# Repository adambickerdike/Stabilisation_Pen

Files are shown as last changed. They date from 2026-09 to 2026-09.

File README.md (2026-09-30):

# Active stabilisation pen: engineering programme

A pen that actively moves its ink tip, and steadies its own body, to counter unwanted hand motion, supports people with Parkinson's-related writing difficulty, assists everyday handwriting and drawing, and captures notes with source-grounded AI assistance.

This repository holds the research and development package: the audit of the source report, evidence, requirements, physics, simulation, mechanics, electronics, firmware, ML, app, validation plans and decisions.

**Evidence status.** Everything here is **calculation, simulation, literature or proposed design**. Nothing has been built, and there are **no physical or human measurements**. Every figure carries a stamp saying what it is, and every result file records its code revision, parameter version, seeds and command.

**Astra publication handoff:** [PDF, GitHub-readable report, reproduction commands and result locations](docs/reviews/2026-09-30_astra_handoff.md). This publishes the implemented pass based on `4ad62b6`, including its corrected numerical evidence and explicit limitations.

**Implemented engineering review, 30 September 2026:** Start with [the new improvement report](docs/engineering_improvement_2026_09_30.md) and the detailed [integration audit](docs/integration_improvement_audit.md). The working tree now includes corrected mechanical load/support models, an extended-travel nib candidate and CAD, a grounded coarse-stage design, causal sensing and controller revisions, constrained accepted-text execution, and explicit correction acceptance. New experiments, rejected RL candidates, source hashes and verification reports are in `results/improvement/`. These are distinct models and evidence levels; do not combine their best numbers into a claim about one built pen. Historical results below remain available for comparison and require the qualifications in the new report.

**Independent review, 29 September 2026:** Read [the research and engineering review](docs/independent_research_review_2026_09_29.md) before using the earlier headline performance or runtime figures below. The later [integrated Rev J simulation, sections 5 and 8](docs/revJ_simulation.md) reports a static nib-load problem omitted by the earlier nose optimization: autowrite nose-coil power changes from 0.09-0.17 W in the simplified study to 2.13 W in the integrated study. Independent statics reproduce approximately 4.717 / 1.628 / 0.166 W of holding loss at 35 / 50 / 75 degrees with the stated geometry. These are calculations on unmeasured inputs, not hardware results. The review prioritizes load balancing, real page-relative sensing, an optional collar/body experiment, and equal-mass comparisons for the inertial tail. Earlier studies remain here as historical evidence; their claims require reconciliation with the integrated findings.

## Start here

| If you want… | Read |
|---|---|
| **On your computer:** open `START_HERE.html` for one-click links to the claims register, the explainer, the spelling prototype and the latest studies | `START_HERE.html` |
| **The latest improvement work:** proposed fine nib, grounded accepted-writing mechanism, causal controllers, physically constrained planning and verification | [`docs/engineering_improvement_2026_09_30.md`](docs/engineering_improvement_2026_09_30.md) |
| **Users and market (round 5, study U):** do people still write by hand, who would pay, what the alternatives are, the go/no-go criteria and the pen vs typing vs dictation comparison | [`docs/market_and_users.md`](docs/market_and_users.md); instruments in [`results/market/`](results/market/) |
| **The nib, optimised (round 5, study N):** Rev K's nib and the independent pass's candidates under one matched model, a search of 13,200 designs, and the recommended ±1.5 mm nib with CAD | [`docs/nib_optimisation.md`](docs/nib_optimisation.md); STEP files in [`results/nibopt/`](results/nibopt/) |
| **The first bench build (round 5, study H):** what to buy and build first, what it costs, how long it takes and what each test decides | [`docs/bench_build_plan.md`](docs/bench_build_plan.md); parts lists and templates in [`results/benchbuild/`](results/benchbuild/) |
| **A moving-paper writing surface (round 5, study P):** a desk platen that moves the paper under the pen, for severe tremor (reach) and for writing accepted words without pushing the hand; simulated on real recorded writing and tremor, with CAD | [`docs/platen_concept.md`](docs/platen_concept.md); results and STEP in [`results/platen/`](results/platen/) |
| **Which earlier results survive realistic sensing (round 5, study X):** the headline simulations rerun with causal sensing, the corrected nib loads and page model v2, case by case after reproducing the old numbers first; six code defects found and fixed (DEC-076) | [`docs/rebaseline.md`](docs/rebaseline.md); results in [`results/rebaseline/`](results/rebaseline/) |
| **The current upstream baseline, Rev K:** integrated balanced nib, its layout and unresolved fit/sensing issues | [`docs/revK_design.md`](docs/revK_design.md); read the new improvement report before quoting its budgets |
| The earlier Rev J design: ±6 mm moving nose, optional grounded heel and reaction-mass tail; historical whole-pen simulations | [`docs/revJ_concept.md`](docs/revJ_concept.md); plan [`docs/revJ_plan.md`](docs/revJ_plan.md); integrated design [`docs/revJ_design.md`](docs/revJ_design.md); the 3-D explainer [`viewer/explainer/`](viewer/explainer/build.py) |
| The Rev J studies | tip [`docs/nose_v2.md`](docs/nose_v2.md), heel [`docs/grounded_drive.md`](docs/grounded_drive.md), tail [`docs/inertial_endcap.md`](docs/inertial_endcap.md), algorithms and AI [`docs/ai_control_v2.md`](docs/ai_control_v2.md), physics simulator [`docs/sim_v2.md`](docs/sim_v2.md) |
| The previous design, Rev H (bigger grip, ±3 mm nose): what is inside, how much it helps each condition | [`docs/revH_concept.md`](docs/revH_concept.md) |
| The recommended route: what to build, where custom hardware and our own data are unavoidable, what evidence each benefit needs | [`docs/recommendation.md`](docs/recommendation.md) |
| The slim pencil variant (Ø8.9 × 166 mm): exact forces, mechanisms with existing parts, what to make, AI guidance and autocorrect, sim-to-real, 3D replay | [`docs/pencil_concept.md`](docs/pencil_concept.md), [`viewer/`](viewer/build.py) |
| The verdict on the source report | [`docs/audit.md`](docs/audit.md), [`docs/corrections.csv`](docs/corrections.csv) |
| **Which numbers still stand:** every headline claim with its status (current, suspended, unproven) | [`docs/claims_register.md`](docs/claims_register.md) |
| The independent review of 29 September 2026 and our response to each finding | [`docs/reviews/`](docs/reviews/2026-09-29_review_response.md) |
| Current state, blockers and next actions | [`CHECKPOINT.md`](CHECKPOINT.md) |
| The system and its budgets | [`docs/architecture.md`](docs/architecture.md), [`docs/icd.md`](docs/icd.md) |
| Why things are the way they are | [`docs/decisions.md`](docs/decisions.md) (DEC-001…099) |
| What the simulations say | [`docs/sim_report.md`](docs/sim_report.md) |
| What may be claimed for each feature | [`docs/features.md`](docs/features.md) |
| The riskiest open questions | [`docs/research_questions.md`](docs/research_questions.md) |
| How to proceed | [`docs/plan.md`](docs/plan.md), [`validation/`](validation/README.md) |

## Historical conclusions and study summaries

The studies below used different mechanisms, sensor assumptions and evaluation protocols. Their numbers are preserved for provenance. The report linked above identifies changed code and the experiments that were actually rerun; a passing software test does not validate an older physical or clinical claim.

> **Correction, 29 September 2026.** The moving nose's coils must hold the ball against a static sideways push from the paper. The refill spring presses the ball along the tilted pen, and the paper pushes back partly sideways. This was left out of the power budgets.
>
> - **Rev J (C1S nose):** it costs 4.7 / 1.6 / 0.17 W at 35 / 50 / 75° pen angle (CALC; confirmed by the physics simulation and by an independent review). The coils would overheat within about a minute.
> - **Rev H (longer arm):** 0.13 W at 50° or more (CALC).
> - **What is suspended:** every battery and heat claim for Rev H, Rev J and Rev J.1. A load-balanced nib is being designed (study B).
>
> **Fix designed, 30 September 2026 (study B, DEC-050; CALC and SIM, nothing built).** A balanced nib, B1, carries the load mechanically. The refill slides ±1 mm on four thin wires, and its spring pushes the refill's rear end through a small face kept parallel to the paper, so the spring's push and the paper's push cancel at any angle. Holding heat is at most 1.6 mW (limit 100 mW), continuous power 7.6 mW, about 38 h per charge (CALC). The cost is reach: ±1.06 mm instead of ±6 mm, so the pen can no longer write whole words for the user (autowrite); that stays a bench research mode. The next prototype, **Rev K**, is the Rev J body with this nib, no heel wheel in the base pen and no tail.
>
> **Rev K laid out, 30 September 2026 (study K, DEC-062…066; CALC, nothing built).** Putting B1 into a whole pen found three things it could not do as drawn: its coils did not fit the bore at the stop, its moving coils had no leads, and the counter-face's push would buckle its wires. Rev K fixes them (coils that can be wound, beryllium-copper wires that double as the leads, a ball thrust guide), at about 2.2 × the copper loss. Rev K is 145.1 mm long, weighs 66.4 g and writes about **24–49 h per charge** with 1 mm of tremor; the finger over the coils stays below 38 °C in a 30 °C room. Of 59 fit checks, 9 fail and 21 are marginal: among them, the page sensor loses the page above 0.2 mm of lift, the fresh ink is harder to see than on Rev J.1, and the fingers sit 3.3 mm closer to the paper at a flat angle (`docs/revK_design.md`).
>
> Check [`docs/claims_register.md`](docs/claims_register.md) before quoting any number.

1. **The transverse load is dominated by N·cos θ, not friction** (COR-01). Holding power (F/(n·K_m))² therefore rules out direct drive at the tip (about 12 W). A front-pivot lever with a rear annular actuator brings it to about 0.5 W in contact at the design point. That is **above the 0.412 W a moving coil can dissipate continuously** (within it on average at 65 % pen-down). Skid and bias-actuator variants remain the product path (DEC-003, DEC-008; route in `docs/recommendation.md`).
2. **Intent separation, not mechanics or latency, limits free-writing assistance.**
   - In simulation, the mechanism could remove 70–80 % of tremor-induced ink error (oracle bound 0.22–0.32).
   - The causal estimators tested give no benefit below ~9 Hz on synthetic handwriting.
   - Guided (template) tasks work in simulation: circle 443 → 163 µm, spiral 382 → 112 µm.
   - Whether real handwriting is more separable is the decisive open question (EXP-H01 → E01).
3. **Parkinson's writing difficulty is mainly micrographia.** A ±0.5 mm stage cannot enlarge letters. PD support means cueing, feedback and practice, measured for lasting unassisted benefit, not immediate correction (DEC-002).
4. **Design errors found and fixed in this package** (calculation and simulation):
   - Nib-bounce instability from a measured-force contact feedforward (DEC-011).
   - Voltage-limited 11 Ω coil, rewound to 6 Ω (DEC-012). A later, fuller headroom check found 6 Ω still binds at 3.3 V in the hot, high-force corner (0.5 % of the thermal envelope) and 4 Ω does not; open until EXP-B03 winds both.
   - A thermal model left at the old 0.45 mm air gap: the moving-coil allowable is 0.412 W, not 0.455 W (v0.4.3).
   - Interface errors found by the firmware review: the ICD printed the inverse Jacobian and the wrong actuator-force sign (fixed in ICD v1.3; the simulator and firmware were right). Tilt-dependent γ is now computed from a stored stiffness ratio.
   - An axial suspension layout that closes the actuator gap: the refill now slides in the carrier (DEC-007 rev.).
   - A nose that touched the paper at every writing angle: the refill point now protrudes 5 mm (DEC-018).
   - Inertia understated by a point-mass approximation: 13.7 g, above the 12 g requirement.
   - The research circuit does not fit the 29 mm board in the CAD envelope. The package plan and a 41 mm board fit at 0.65 density (DEC-014, open).
5. **A pencil-sized version is possible only if the writing force bypasses the nib** (`docs/pencil_concept.md`, DEC-019 to DEC-022).
   - A nose skid carries the user's force and a light spring sets the nib force. The stage then holds 0.17 N instead of 0.76 N.
   - Four custom 2.6 mm piezo plates fit the 7.9 mm bore. They give ±277 µm of stroke under load at zero static power, in 12.2 g of CAD before wiring. A voice coil that fits would need 2.4 W.
   - The stroke margin is thin (±162 µm at −20 % tolerance). Tremor estimation is the same open problem as in Rev A. Re-optimising the stage with real parts (P0.2: custom plates, thicker leaves, charge-recovery drive) gives 212 µm in the worst corner instead of none and 2.7 h of assist instead of 0.5 h (`docs/opt_hardware.md`, DEC-030).
   - **The user has since chosen a bigger grip (DEC-029): the primary concept is now Rev H, where the whole front of the pen tilts to move the tip about ±3 mm. The pencil is the slim variant.**
   - The skid causes touchdown and lift tails: about 1.1 mm of extra ink per stroke. A tilt-adaptive front stop cuts this to 0.33 mm. A stage feed-forward in firmware, tuned by adjoint gradients and Bayesian search, then brings the ink at the transitions to 0.005–0.008 mm per stroke; bounce is its open risk (`docs/opt_touchdown.md`, DEC-026).
   - Paper capture needs a ≥ 120 Hz page sensor that does not yet exist at this size.
   - AI helps as a digital autocorrect (word errors 32 % → 10 %). Physical guidance toward AI-predicted letters does not help free writing: a correct prediction is already about 300 µm off, beyond break-even. Guidance toward known templates does help.
   - Weights, gyroscopes or a motorised grip inside the 20 g pencil leave 0.85–0.97 of the ink error with perfect knowledge, against 0.18–0.43 for the nib stage (`docs/inertial_stabilisation.md`). At the user's direction the bigger-grip pen has active inertial control of its body (item 7, DEC-033).
   - The accelerometer now drives the tremor tracker directly, with gyroscope compensation. It leaves 0.78 of the tremor-band error on average, against 0.85 before, and 0.58–0.71 at 8–12 Hz once calibrated per writer. Separating tremor from writing is still the limit (`docs/sensor_fusion_ai.md`, DEC-025). Re-optimising its settings with exact adjoint gradients gives 0.86 instead of 0.91 for the default set, and 0.67 instead of 0.79 at 8–12 Hz; learned trackers were not better at equal false correction (`docs/opt_tracker.md`, DEC-028).
6. **The simulator can be calibrated from the planned bench work, and the twin experiments say how well** (`docs/sim_to_real.md`, DEC-023).
   - On 15 blind simulated plants the protocol experiments recover every model parameter to ≤ 1.6 % in about 1.5 h of bench time per build.
   - The calibrated twin then predicts the oracle ratio within ±0.1 for 14 of 15 plants, against 4–5 uncalibrated.
   - The same work found that the frozen tremor estimator degrades on randomised plants (median ratio 0.88 at 9 Hz), and that the existing Monte Carlo lets the controller see true plant values.

7. **Rev H, the bigger-grip pen, was the primary design until Rev J (item 8)** (DEC-029, DEC-032, DEC-033; `docs/revH_concept.md`). All simulation and calculation.
   - Ø22 × 170 mm, 75 g, or 103 g with the inertial module. The fingers hold a fixed sleeve whose front ring rests on the paper and carries the writing force. The whole front of the pen (the nose, holding the refill) tilts on a flexure gimbal, driven by two pairs of flat voice coils, so the ink tip moves up to ±3 mm: ten times the pencil's stage. About 0.08 W, about 27 h of writing.
   - A rear inertial module (19.8 g tungsten slug moved ±2.75 mm on two axes) pushes the whole pen against the shake. On top of the nose it adds 6–17 % further reduction depending on the grip. It is fitted in the first prototype; the product keeps it if the grip measurement (EXP-I01) and the bench test (EXP-I06) confirm ≥ 10 %. A plain weight made the ink worse in 38–42 % of 8–12 Hz cases and is not used.
   - With perfect knowledge of the tremor the nose removes 87–99 % of the ink error up to 2 mm, and the app reads 98–100 % of words. With today's accelerometer tracker: 22–50 % at 8–10 Hz (words read at 10 Hz, 1 mm: 54 → 87 %), and nothing at 4–6 Hz. **The tracker, not the mechanism, is the limit** (`docs/opt_inertial.md`, `docs/handwriting_outcomes.md`).
   - Parkinson's shrinking letters: a "write bigger" vibration cue kept letters at 5.2 mm instead of 4.2 mm, if people respond as small studies suggest. Poor handwriting: guidance brings the ink 24–61 % closer to the target letters while it is on (partial nose guidance 35 %, reading slightly better; full guidance reads worse); lasting benefit needs a human study (EXP-W04). Dyslexia: guidance never turned a wrong letter into the right one; the help is the app's spelling check, read-back and clean copy.
   - An optional desk board moves a permanent magnet under the paper to pull the pen along whole letters (0.4 N cap; `docs/guidance_board.md`, DEC-031).
   - AI letter prediction does not close the tracker's gap at 1–2 mm tremor: a correct predicted letter is 0.5–0.9 mm off because it is placed where the shaking tip lands; as a tracker input it closed 0 %, as nose guidance 1 %. The app's digital clean copy makes 97 % of words readable at 1–2 mm, against 30–59 % in the ink (`docs/ai_severe_tremor.md`, DEC-035).

8. **Rev J acts at the tip, the heel and the tail; it is now the primary design** (DEC-036…049; `docs/revJ_concept.md`). The user asked for far more physical effect, inertial movement of the whole pen, and a pen that can partly write for you. All calculation and simulation.
   - **The whole pen in the physics simulator (round 2, `docs/revJ_simulation.md`, DEC-046…049; SIM on synthetic writers and synthetic tremor, 6 test writers).** Readable words out of 10, ordinary pen → Rev J: essential tremor 2 mm at 8–12 Hz 5.4 → 10 (1 mm: 10 → 10; the ink error falls to 0.63 of the ordinary pen's); mild 0.3 mm: no change, no harm; **slow 4 Hz tremor: nothing** (the pen cannot yet tell it from writing; perfect knowledge would remove 90 %); severe 3 mm: 0.4 → 3.8 writing through it, 0.4 → 8.8 when the pen writes a text the writer chose (autowrite). Parkinson's practice loops: only the driven heel wheel keeps the last loop big (6.6 → 8.6 mm of 10). Dysgraphia: a half-way nose brings the ink 23 % closer to the copybook letters with no loss of readability. Dyslexia lead-through helps little (5.8 → 6.7); autowrite of the right spelling reads 10 of 10. Tremor-free writing: moved 0 mm by the nose, 0.41 mm by the heel wheel, so **the wheel is retracted by default** (DEC-048). The chosen tracker is the guarded tracker G4 (DEC-047). **Power:** the nose drew about 2.3 W in every mode, mostly to hold the ball against the static side load: writing time per charge is suspended until the load is carried mechanically (DEC-046, study B). RL was not trained yet.
   - **Real recorded data (study R, `docs/real_data.md`, DEC-054, DEC-055; SIM with real recorded inputs).** With real handwriting (UNIPEN: 14 adults with a ballpoint on paper), real Parkinson's tremor recorded at the pen tip, real essential tremor recorded at the hand, and a realistic page sensor, on held-out writers, texts and patients: real tip tremor is smaller than assumed (severe typically 1.7 mm, not 5–10 mm) and about twice as irregular as the model. **No tracker built so far makes the writing more readable on real tremor:** at the severe size, 0.5 of 10 words with an ordinary pen, 0.4 with Rev J's gated tracker, 0.2 with the learned TCN, and 7.0 with perfect knowledge of the tremor (6.8 without tremor). The ±6 mm nose has the reach; estimating real tremor in time is the missing piece. So the synthetic-tremor gains above are not claims about real tremor until a tracker passes on real inputs (DEC-055).
   - **Tracking real tremor (study E, `docs/real_tracker.md`, DEC-060, DEC-061; SIM with real recorded inputs).** Every kind of causal tracker was tried on study R's real inputs (filters, oscillator trackers, the pen's Kalman tracker with new gates, study W's candidate, small networks), tuned on the tuning writers only, frozen, and tested once on 9 held-out writers. **None passes DEC-055 yet.** The winner took about a third off the severe tip tremor (0.69 ×), but about 1 mm was left and words read stayed at 0.5 of 10; and it moved one writer's clean writing 0.49 mm, because that writer's large, fast letters looked like tremor to it. The reasons: handwriting moves in the same 4–8 Hz rhythm as tremor, real tremor wanders, and taking off a third of 1.7 mm is not enough. The delay is not the cause. A small network trained on real recordings looked better afterwards (0.60 ×, clean writing moved 2.5 µm) but must be tested again on new data (EXP-E10). Meanwhile the safe default tracker (G4) stays, help for severe tremor comes from the app (clean copy, spelling, completion), and the next nib stays at ±1 mm.
   - **The readable target and where the gap is (study F, `docs/readable_target.md`, DEC-067…069; SIM with real recorded inputs).** Driving the nose with perfect knowledge of the tremor and then spoiling it on purpose shows how much tremor may be left: **+2 readable words at the severe class need at most about 0.55 mm of the 1.7 mm left at the tip** (0.65 mm on the tuning writers, 0.55 mm on the test writers), and near-normal reading about 0.25 mm; the best causal tracker leaves 1.12 mm. **Predicting the tremor is not the problem** (over the pen's 4.9 ms horizon a simple predictor leaves 0.03 mm); **telling tremor from writing is**: with the tremor alone the pen's accelerometer gets to 0.29 mm, but once the person writes every estimator either backs off (about 1 mm left) or moves the writing. Calibrating the gate on each writer's own clean writing, raise-only, kept every writer's clean writing within 19 µm (information only). **Reach:** with a ±1 mm nib even perfect knowledge gains only 1.4 words at the severe class; ±1.5 mm gains 3.2, and a real tracker would need about ±2–3 mm. So Rev K's nib is for mild-to-moderate tremor and for proving the balanced nib; severe tremor needs both a separating estimator and more reach.
   - **Spelling help, prediction and clearer writing (study S, `docs/spelling_and_clarity.md`, DEC-056, DEC-057; CALC and SIM on real letters and real misspellings).** A separate language layer with three outputs (the ink, the transcript, and the pen's writing plan). Letters are read while they are written (82 % by the end of each letter for unseen writers). The spell checker catches 63 % of real children's misspellings when the letters are known (34 % when the pen reads them itself) at about 2 false alarms per 100 words; a tick at the next pause gets 3 of 10 misspellings fixed on paper (writer responses assumed). Word completion puts the word in the top 3 after one letter 52–56 % of the time. The shape assist does not make letters clearer (41.4 → 41.9 %), so it is not adopted; nearest-point close tracing is retired because it left parts of letters undrawn. The pen writes only text the writer accepted, and needs about ±4–6 mm of reach for a whole word. A prototype page to try it is in `ai3/demo/index.html`.
   - **Shifting the whole pen (study W, `docs/whole_pen_shift.md`, DEC-051…053; CALC and SIM).** At the user's request the study designed the strongest compact way to physically shift the whole pen: a collar you hold, with the inner pen swinging on a hinge 50 mm behind the tip, driven by a flat coil in the collar's back wall (±4 mm at the tip, 21.7 mm across, 40.1 g, only 0.055 W to hold at 50°). Weights, gyroscopes and pushing on the paper cannot do this job in a pen. **In simulation the collar did not beat Rev J's moving nose**, which already reaches ±6.57 mm (−5 % to +5 % against the same pen with the collar locked; the gate is 10 %), so the moving nose stays the part that shifts the ink, the collar is a bench experiment, and inertial tails are rejected for the product (DEC-051). What would make writing much better is knowing the tremor: at 3 mm, perfect knowledge leaves 0.14–0.24 mm and every word readable, against 1.1–1.4 mm with today's estimate (DEC-052).
   - **The balanced nib (study B, `docs/balanced_nib.md`, DEC-050; CALC and SIM).** Eleven ways to carry the paper's static sideways push were designed and optimised for the 24 mm pen and a 12–16 mm core. The winner, B1, is a two-axis translation nib on four titanium wires with flat moving coils (no magnetic pull) and a contact-driven counter-face that cancels the push at every tilt and roll (residual 5.3 mN, 6 % of the load). It holds with at most 1.6 mW and runs on 7.6 mW (Rev J's nose: 1.6 W at 50°); in the physics simulator it removes as much tremor as Rev J's nose up to 1 mm (words read 6.4 → 8.1 of 10, 8.9 with perfect knowledge) and never moved clean writing. Its reach is ±1.06 mm (a ±1.5 mm option doubles its small power). The biggest unknown is the lowest ink force a ballpoint writes with, which sets the power (8 mW at 0.15 N, 184 mW at 0.69 N). A slim core works only with piezo benders (±0.56 mm).
   - **The Rev K layout (study K, `docs/revK_design.md`, DEC-062…066; CALC, one SIM check).** B1 placed in the Rev J body with every part fitted, budgeted and drawn (CAD with STEP): 145.1 mm, 66.4 g (73.4 g with the heel module), balance point 74.9 mm from the tip; 23.5–48.6 h per charge with 1 mm tremor, 10.8–15.0 h of lead-through with the heel module; web 30.6 °C and front finger pad 35.9–37.6 °C in a 30 °C room; 226–501 USD per pen at 1,000 (assumption-heavy). It needed a buildable coil (force constant 0.334 N/√W, an upper bound), C17200 wires as the coil leads (beryllium: soldered or crimped only), a ball thrust guide for the counter-face couple, a counter-face head with three piezo motors, and a slower servo (40 / 46 Hz: +7 % ink error on tuning writers). The pen lift (0.5 mm in 0.18 s) serves the spelling cue. The heel wheel becomes a separate bench front (DEC-065). 9 of 59 fit checks fail.
   - **Physics first.** A handheld pen can push the hand only against a mass inside it, against the hand itself, or against the paper. A moving mass gives F = m(2πf)²X, which is tiny at handwriting frequencies (below about 5 Hz): the best 45 g end-cap moves the ink at most 0.21 mm and a gyroscope 1.06 mm, against the 2 mm needed (SIM). The paper, used as ground through a small wheel at the heel, gives 0.3–0.6 N on the hand (CALC on an assumed tyre friction, to measure in EXP-D01).
   - **Tip (nose v2, DEC-036).** The refill tilts on a gimbal 76.5 mm behind the ball, driven by a 2 × 2 magnet checkerboard across a spherical gap: ±6.0 mm of ball travel guaranteed over 35–75° of tilt (Rev H ±2.75 mm), in a Ø24 handle. A pen lift (electro-permanent brake and latch) separates strokes. **Autowrite** (a mode the user turns on) writes a known text in the writer's style while the hand sweeps along the line: 99.2 % of letters and 100 % of words read with up to 1 mm of tremor, 98 % at 2 mm; 2.5 mm letters at 3.7 letters/s (SIM).
   - **Heel (paper-grounded drive, DEC-037, DEC-048).** A 2 mm wheel in the skid ring; the first studies steered it by default (the cobot principle: it keeps the hand on the letter's path and cannot move the pen by itself); it is now retracted by default (above). In the simpler HW1-D model, Parkinson's "write big" loops reached 0.99 of the target height with steering alone (0.78 with nothing; contested by the physics simulation, where only the driven wheel kept the last loop big); tracing error 582 → 76 µm with the nose, although letters read fell from 92 % to 79 % (closer to the template is not more legible); lead-through drew a letter bowl within 0.3 mm in 93 % of runs. A writer who resists always wins: a letter the writer is set on was never turned into another (0 %).
   - **Tail (reaction-mass end-cap, DEC-038, DEC-045).** A tungsten slug moved ±4 mm on 5 Hz flexures in a detachable end-cap: in the simpler H1 model a further 5.6 / 16.8 / 18.3 % tremor reduction on top of the nose at grip splits 0.3 / 0.5 / 0.7 with Rev J.1's 29.6 g end-cap (8 / 18 / 20 % with the first 43 g design), and cues in pauses; **in the physics simulation, no gain** (0.67 of the ordinary pen's error with it, 0.65 without), and study W's tails never robustly beat the same mass locked, so **inertial tails are rejected for the product** (DEC-051). It cannot steer letters.
   - **Algorithms and AI (DEC-042, DEC-043, DEC-047).** In the simpler HW1 model a tremor-line detector switching on a listening (fixed-lag Kalman) tracker gave, for essential tremor 1–2 mm at 6–10 Hz, ink error 830 → 430 µm (Rev H's tracker 627) and words read 31 → 74 %, including 6 Hz where Rev H did nothing; in the physics simulation this tracker moved tremor-free writing by 59 µm (rule 25 µm), so the guarded tracker G4 replaces it there. A causal TCN reaches 278 µm but stays in shadow mode until real recordings. Delayed ink and next-letter steering did not help, and RL driving the nose read more words but moved clean writing too much; RL is used offline to design shared control. The app gains word completion and labelled style synthesis.
   - **Simulator v2 (DEC-040).** MuJoCo physics of the hand, pen, moving nose, refill and paper, with the heel wheel and end-cap as plug-ins, domain randomisation and a Gymnasium environment. On the earlier hand–pen model's 56 test cases it reproduces the uncorrected ink error within 3.1 % in every case, the perfect-knowledge ratio within ±0.03 in 52 and the tracker's ratio within ±0.05 in 50 (the misses are the Rev H tracker's frequency lock, not the plant); it converges and conserves energy; it also showed that the synthetic writers write at half adult speed with about ten times the measured 8–12 Hz motion, which makes tremor separation look harder than it probably is (refit on recordings, EXP-V03). Until bench identification, it ranks designs only (ASME V&V 40 context COU-1).
   - **Integration and Rev J.1 fixes (DEC-044, DEC-045; CALC).** Rev J.1 is Ø24 × 143.9 mm and 84.3 g, or 161.9 mm and 112.7 g with its lighter end-cap (target 120 g). It fixes what the first layout found: 75 µm gimbal strips carry the 12–22 N magnet pull (buckling 55 N); a low-power page sensor and datasheet-counted electronics give 8.5–9.7 h at 1 mm tremor; a 0.1 mm graphite sheet keeps the skin at 35.9 °C in a 30 °C room; a clear window shows the ink near the ball in 47 % of tilt × eye cases (was 22 %). All battery and heat numbers rest on the nose-coil power model, which left out the static side load; they are suspended (the physics simulation measured about 2.3 W).
   - **Round 4 (running, `docs/round4_plan.md`).** At the user's direction: shifting and pivoting the whole pen against large Parkinson's and essential tremor (gyroscopic tail, tuned mass, pivot grip, paper-grounded force, ink only when in reach); real recorded handwriting and tremor as simulation inputs; a physical spell checker, better word prediction and shape assist; results shown as one understandable number per condition.
   - **Measurement rigs (study M, `docs/measurement_rig.md`, DEC-058, DEC-059; PROPOSED DESIGN, CALC, synthetic checks).** Six bench rigs on one data-acquisition box and a converted 3-D printer, in the order the independent review asks: R9 contact and ink (gate G1: the lowest refill force that writes, the axial and paper-normal forces measured apart, and the static side load; it also runs EXP-J17), R10 page sensing on paper against DeltaPen, R11 recording pen and tablet protocol (real tremor and writing forces), R12 actuator coupons (G2), R13 loaded nib (G3, G4) and R14 grip simulant (G5: a moving collar or tail against the same mass locked). No rig exists yet; the firmware is written but not compiled for the board.
   - Rev H corrections found on the way (DEC-041): the nose actuator's force constant is 0.19 N/√W by an image-method model, not 0.47; the refill's front stop must follow the nose; the ink-force spring needs a fatigue rating.

**Where the simulations are, and what the optimisation studies found:** [`docs/optimisation.md`](docs/optimisation.md). The 3D replay page is `viewer/index.html` (`python3 viewer/build.py --variant Q`); the Rev J explainer is `viewer/explainer/index.html` (`python3 viewer/explainer/build.py`).

## Completion table

States: **drafted** (text or design, not run) · **executable** (code runs, results depend on unverified inputs) · **executed** (run here; outputs in `results/`) · **hardware pending** · **measured** (none yet).

| Brief area | Deliverable | State | Evidence |
|---|---|---|---|
| 1 Research | Audit and recalculation of the report (37/37 numbers reproduce; 28 corrections) | executed | `analysis/audit_recalc.py` → `results/audit/` |
| 1 Research | Evidence ledger (795 sources, 8 streams) and synthesis | drafted | `docs/evidence.csv`, `docs/research_synthesis.md` |
| 1 Research | Ranked research questions with decisive experiments | drafted | `docs/research_questions.md` |
| 2 Mechanics | Parametric CAD (Rev A, Rev A.1) with interference checks, STEP, drawings | executed | `mechanics/cad/`, `results/cad/` |
| 2 Mechanics | Flexures, tolerance stacks (S1–S6), mass/CoM budget, configuration trade | executed | `mechanics/`, `results/mechanics/`, `results/trade/` |
| 2 Mechanics | Stage-A loaded bench rig (dimensioned concept CAD) | executed (design) · hardware pending | `mechanics/cad/bench_rig.py`, `results/cad/drawing_bench_rig.png` |
| 3 Electronics | KiCad 8 schematic: 11 sheets, regenerated deterministically; ERC 0 errors; netlist cross-check pass; PDF; BOM with VERIFY/SELECT | executed | `electronics/kicad/`, `electronics/bom_revA.csv` |
| 3 Electronics | Drive/sense calculations, including the supply-headroom assessment of the winding (6 Ω binds at 3.3 V in the hot, high-force corner; 4 Ω does not); ngspice drive stage incl. fault; placement study | executed | `electronics/calcs/`, `electronics/spice/`, `results/electronics/` |
| 3 Electronics | PCB layout and fabrication outputs | **not started** (blocked by DEC-014) | `electronics/README.md` E-1 |
| 4 Simulation | Coupled pen–hand–paper model M1: 12 verification tests; tuning/test split; grid, Monte Carlo, sensitivity, failures, design sweeps, frequency-gate diagnostic | executed | `sim/`, `results/sim/`, `docs/sim_report.md` |
| 4 Simulation | EM field models; thermal network with a two-node reduction for the firmware governor | executed | `analysis/`, `results/em/`, `results/thermal/` |
| 4 Simulation | Validation plan per model | drafted | `docs/physics.md` (table), `validation/` |
| 5 ML | Synthetic data pipeline with writer-disjoint splits; six conventional baselines tuned on validation; causal TCN; int8 quantisation (no loss); C export bit-exact with the Python reference, also on emulated Cortex-M33; MCU budget (exported model without f_est: 16.2 k MAC, 7.3 kB weights, 0.58 kB RAM); model and dataset cards; 22 tests | executed (synthetic only) · real data pending (EXP-H01) | `ml/README.md`, `results/ml/` |
| 6 Firmware | C control core: 40 kHz current loop, 2 kHz stage task, Kalman and band-pass estimators, guided mode, Jacobian with tilt-dependent γ, two-node thermal governor, safety state machine, ML guard (ICD §5 v1.2), calibration records, ICD log writer. Parameters generated from the YAML with a freshness check; golden vectors and replays from the simulator; 60 test cases (1120 checks) pass on host (ASan/UBSan) and on emulated Cortex-M33; nRF5340 image builds (32.3 kB flash). Register-level drivers are stubs marked VERIFY | executed (host, emulator, build) · hardware pending | `firmware/README.md`, `results/firmware/` |
| 6 Product | ICD log reader/writer with CRC and resync (parses the firmware's golden log with zero issues); immutable content-addressed note store with provenance-carrying derived layers; segmentation; SVG rendering; recogniser interface (on-device adapter specified); FTS5 search with stroke citations; grounded assistant that refuses unsupported, uncited or clinical answers; capture-fidelity analysis; digital autocorrect as a derived layer; 147 tests | executed (synthetic data) · real recogniser pending | `app/README.md`, `results/app/` |
| 7 Validation | 227 experiments with criteria (172 bench/offline, 55 human) with procedures, equipment, uncertainty and decision rules, including the Rev J and Rev J.1 studies (EXP-D, K, N, L, V, J); 755 acceptance criteria (297 requirement, 135 derived, 323 hypothesis; checker passes) against 218 requirements; prototype stages A–D with gates; human study plan separating immediate assistance from lasting improvement; review of 33 document inconsistencies, now resolved or recorded | drafted · hardware and participants pending | `validation/README.md` |
| Pencil | Pencil-class concept: CAD (Q and L layouts, fit checks, STEP, drawings), mechanism study (forces, 12 mechanisms, drive power, drop), pencil model P1 (skid, spring-loaded refill, piezo stage; exact match with M1 when locked), page-sensor rate study, touchdown tails | executed (design, calculation, simulation) · hardware pending | `docs/pencil_concept.md`, `docs/pencil_mechanisms.md`, `mechanics/cad/pencil_revP.py`, `sim/pencil/`, `results/pencil/` |
| Pencil | AI prediction and guidance (text predictor, style templates, stroke continuation, closed loop on P1 and M1, deployment and ICD proposal) and app autocorrect | executed (synthetic data) · people pending (EXP-A02/A03) | `docs/ai_guidance.md`, `aiguide/`, `results/ai/` |
| Pencil | Inertial and pivot stabilisation study: hand-pen model H1 with pen tilt in a two-zone grip; weights, gyroscopes, CMGs, reaction wheels, grip sleeve, passive pivots | executed (simulation, calculation) · grip measurement pending (EXP-I01) | `docs/inertial_stabilisation.md`, `sim/handpen/`, `results/pencil/inertial*.json` |
| Pencil | Sensing and AI estimation: IMU parts and lever arm, acceleration-domain Kalman, WFLC/BMFLC, learned GRU, template prior, 20 s personal calibration, closed loop on P1 | executed (simulation) · real data pending (EXP-H01/E01) | `docs/sensor_fusion_ai.md`, `fusion/`, `results/fusion/` |
| Pencil | Slim pencil hardware optimisation (P0.2): differentiable design model (exact against design.py and the CAD), adjoint gradients, Bayesian optimisation and CMA-ES over real and supplier-standard parts, finalists ranked in P1, BOM, CAD with STEP | executed (calculation, simulation) · custom plates to quote (EXP-Q04) | `docs/opt_hardware.md`, `opt/hardware/`, `results/opt/hardware.json` |
| Pencil | Tracker optimisation: differentiable accelerometer Kalman filter (PyTorch, and a hand-written numba adjoint), tuning of all 23 settings by backpropagation through time, Pareto front against false correction, learned trackers on the tremor band, per-writer gradient tuning; recorded-data pipeline | executed (simulation) · real writing pending (EXP-E01) | `docs/opt_tracker.md`, `opt/tracker/`, `results/opt/tracker.json` |
| Pencil | Touchdown and lift optimisation: stage feed-forward, stop margin and servo retune; adjoint gradients of a differentiable reduced model (torch), ParEGO Bayesian optimisation and CMA-ES on P1; faster slide-sensor option | executed (simulation) · bench pending (EXP-Q08) | `docs/opt_touchdown.md`, `opt/touchdown/`, `results/opt/` |
| Pencil | 3D replay page of the simulated pencil with generated tables | executed | `viewer/` (`python3 viewer/build.py`) |
| Rev H | Bigger-grip pen: tip design A against B, adjoint design of the nose actuator, ParEGO tracker for ±3 mm, rear inertial module, gyroscope and passive-weight options, neural reaction-mass controller, envelope tiers, CAD with STEP (with and without the module), BOM, power; H1 extended with regression tests | executed (calculation, simulation) · grip and bench pending (EXP-I01, I05, I06) | `docs/opt_inertial.md`, `opt/inertial/`, `mechanics/cad/revH_pen.py`, `results/opt/inertial_opt.json`, `results/revH/` |
| Rev H | Handwriting outcomes per condition (essential tremor, Parkinson's micrographia, poor handwriting, dyslexia) in model HW1, cross-checked against P1; scorer for real recordings | executed (simulation) · people pending (EXP-W01…W05) | `docs/handwriting_outcomes.md`, `handwriting/`, `results/handwriting/` |
| Rev H | Guidance board: architecture comparison, magnet force maps, stage, Hall sensing, guidance control, CAD, BOM | executed (calculation, simulation) · hardware pending (EXP-G01…G07) | `docs/guidance_board.md`, `board/`, `mechanics/cad/guidance_board.py`, `results/board/` |
| Rev H | 3-D explainer: components, how it moves, before/after writing, evidence level of every number; smoke test | executed | `viewer/explainer/` (`python3 viewer/explainer/build.py`) |
| Rev H | AI help for severe tremor: letter prediction as a tracker prior and as nose guidance, a severe-tremor tracker setting, the app's digital clean copy; safety (wrong letters, agency, false correction); rules fixed on tuning writers | executed (simulation) · recordings pending (EXP-W02, EXP-A03) | `docs/ai_severe_tremor.md`, `aiprior/`, `results/aiprior/` |
| 4 Simulation | Sim-to-real: virtual bench with instrument models, blind identification of 15 plants in protocol order, bench-time study, calibrated-twin prediction gap, model-form diagnostics, piezo hysteresis identification, domain randomisation, hardware-in-the-loop specification; 22 tests | executed (twin experiments) · bench pending | `docs/sim_to_real.md`, `validation/sim_to_real.md`, `s2r/`, `results/s2r/` |
| Rev J | Plan and plain-words concept: what acts at the tip, heel and tail, results per condition, modes, whether it can write for you, what to test first | drafted | `docs/revJ_plan.md`, `docs/revJ_concept.md` |
| Rev J | Study D, paper-grounded heel drive: traction over the writer population, tyre mechanics, driven ball, omni-wheels, steered and braked wheels, controllable friction; differentiable design optimisation; guided, lead-through and resisting-writer runs; force cap and lateral release; CAD | executed (calculation, simulation) · friction and bench pending (EXP-D01…D07) | `docs/grounded_drive.md`, `drive/`, `results/drive/`, `mechanics/cad/heel_drive.py` |
| Rev J | Study K, inertial end-cap: force ceilings, CMA-ES and autograd design of reaction masses, gyroscopes (CMG), reaction wheels and pseudo-force cues; tremor on top of the nose; letter steering; CAD | executed (calculation, simulation) · grip pending (EXP-I01, K08) | `docs/inertial_endcap.md`, `endcap/`, `results/endcap/`, `mechanics/cad/endcap.py` |
| Rev J | Study N, nose v2: magnet-array field models (magpylib), CMA-ES and adjoint optimisation over multi-pivot and multi-coil candidates, front-end closure at ±3–8 mm, pen lift, autowrite planner and test grid; CAD | executed (calculation, simulation) · coupons pending (EXP-N01) | `docs/nose_v2.md`, `nose2/`, `results/nose2/`, `mechanics/cad/nose2.py` |
| Rev J | Study L, AI and control v2: tremor-line gate, gated listening tracker, learned estimators (TCN, transformer, hybrid), delayed ink, RL (PPO, SAC) in Gymnasium, next-letter and next-word prediction, sigma-lognormal style synthesis, shared-control arbitration | executed (synthetic data) · recordings pending (EXP-H01, EXP-L01…L08) | `docs/ai_control_v2.md`, `ai2/`, `results/ai2/` |
| Rev J | Study V, simulator v2: MuJoCo 3.6 hand–pen–paper model with the H1 contact law, reproduction of H1, time-step convergence, energy balance, gyroscope check, MyoSuite impedance, literature validation, Gymnasium environment with domain randomisation, plug-ins; ASME V&V 40 contexts of use | executed · bench identification pending (EXP-V01…V06) | `docs/sim_v2.md`, `sim2/`, `results/sim2/` |
| Rev J | Integrated design: front end, placement along the pen, refill and pen lift, mass, power, heat and cost budgets, magnetics, 38 fit checks, simulator parameters, CAD with STEP | executed (calculation) · hardware pending | `docs/revJ_design.md`, `revj/`, `results/revJ/`, `mechanics/cad/revJ_pen.py` |
| Round 4 | Study B, the balanced nib (after the independent review): eleven load-balancing mechanisms designed for the 24 mm pen and a 12–16 mm core, magnetics, flexures, fatigue, thermal and ink-force models, multi-objective optimisation, closed-loop simulation in sim2, CAD of the recommended nib B1, interface file `config/nib.yaml` | executed (calculation, simulation) · bench pending | `docs/balanced_nib.md`, `bnib/`, `results/bnib/`, `mechanics/cad/bnib.py` |
| Round 4 | Study W, shifting the whole pen against large tremor: tremor targets, grip pivoting, collar, tuned masses, gyroscopes, paper-grounded force and write-when-in-reach designed and optimised; closed-loop simulation against the same pen locked at three grips; real tremor sizes; CAD of the reference collar | executed (calculation, simulation) · bench pending | `docs/whole_pen_shift.md`, `wholepen/`, `results/wholepen/`, `mechanics/cad/wholepen.py` |
| Round 4 | Study S, spelling help, prediction and clearer writing: causal streaming letter recogniser, recognition-aware spell checker from real misspellings, physical cues, personal word completion, why close tracing lowers legibility, shape assist, accepted-word writing planner, three separated outputs; a self-contained prototype page | executed (calculation, simulation) · people pending | `docs/spelling_and_clarity.md`, `ai3/`, `results/ai3/` |
| Round 5 | Study N, the balanced nib optimised: the four existing nib designs under one matched model (gravity, face residual, writing drag, guide drag, nonlinear wires, fin-model temperature, weakest-point force constant × 0.7), guide-topology screen, NSGA-II search of 13,200 designs over reach, body, magnets, winding, wires, anchor, guide and moving mass, four candidates with CAD and pen budgets | executed (calculation) · coupon pending (EXP-NB01) | `docs/nib_optimisation.md`, `nibopt/`, `results/nibopt/`, `mechanics/cad/nibopt.py` |
| Round 5 | Study U, users and market: sourced prevalence and handwriting-use evidence, sizing model, competitor scan, customer-discovery pack (interview guides, survey, waitlist plan, recruitment and ethics), pre-registered go/no-go criteria, the pen vs typing vs dictation comparison design, business-model order | executed (literature and calculation) · discovery pending (EXP-U01…U06) | `docs/market_and_users.md`, `results/market/` |
| Round 5 | Study H, the first bench build plan: parts lists per gate with sourced prices, fabrication, safety (beryllium, magnets, the five-bar), test-to-decision map, budget and 12-week schedule, blank data templates, a synthetic pipeline check through the rig analyses | executed (plan) · nothing bought yet | `docs/bench_build_plan.md`, `results/benchbuild/` |
| Round 5 | Study P, the moving-paper platen: concept with sourced parts (voice-coil fine stage on a belt coarse stage, vacuum plate, palm rest, camera tip sensing, Z-drop lift), a moving-page plant coupled to HW1, tremor cancellation on real recorded inputs against the ±1.0 and ±1.5 mm nibs, accepted-word writing against the five-bar, sensitivity to friction coupling, camera and stage, product fit, CAD with STEP | executed (simulation with real recorded inputs, calculation) · bench pending (EXP-PL01…PL09) | `docs/platen_concept.md`, `platen/`, `results/platen/`, `mechanics/cad/platen.py` |
| Round 5 | Study X, the re-baseline: an impact register of all 69 simulation claims (29 rerun, 15 affected but not rerun with reasons, 23 unaffected, 2 superseded); sim2j's cards with causal sensing (Rev J + G4 0.61 of the ordinary pen, was 0.63), the balanced nib in sim2 with DEC-066's servo and the corrected loads, study F's reach with B1's servo and mass (±1.5 mm needed), studies R, E and F under page model v2 (conclusions stand); six defects in imported packages, fixed in their packages (DEC-076; full suite 958 passed) | executed (simulation, reproduction checks first) · bench pending (EXP-X01…X09) | `docs/rebaseline.md`, `rebaseline/`, `results/rebaseline/` |
| Round 4 | Study F, the readable target: tremor left at the tip against words read (amplitude, lag and random residuals; frozen on tuning writers, tested once), per-user gate calibration (information only), prediction vs sensing vs separation, the reach a nib needs | executed (simulation with real recorded inputs) · people pending (EXP-E20) | `docs/readable_target.md`, `readable/`, `results/readable/` |
| Round 4 | Study K, the Rev K integrated layout: B1 in the Rev J body, buildable coils, C17200 wire leads, ball thrust guide, counter-face head and pen lift, 59 fit checks, centring tolerances, mass, power and battery per mode, skin temperature, nib modes against the 2.5 × rule, cost, heel module, simulator parameters; CAD with STEP; a servo-bandwidth check in sim2 | executed (calculation, one simulation check) · bench pending (EXP-K20…K25) | `docs/revK_design.md`, `revk/`, `results/revK/`, `mechanics/cad/revK_pen.py` |
| Round 4 | Study E, tremor tracking on real data: filters, WFLC/BMFLC, oscillator trackers and EPLL, Kalman trackers with new gates, study W's GLG, networks trained on real and synthetic writing; delay analysis; pre-registered choice frozen on tuning writers and tested once on held-out writers; MCU cost | executed (simulation with real recorded inputs) · none passes DEC-055 | `docs/real_tracker.md`, `realtrack/`, `results/realtrack/` |
| Round 4 | Study R, real recorded data: real handwriting (UNIPEN hpb2, chosen by a kinematics rule), real Parkinson's and essential tremor, severity classes at the pen tip, a measured-error page sensor, a literal handwriting reader (TrOCR); held-out writers, texts and patients; the bridge from synthetic to real inputs; licences respected (only statistics of restricted data committed) | executed (simulation with real recorded inputs) | `docs/real_data.md`, `realdata/`, `results/realdata/` |
| Rev J | Study M, measurement rigs for the review's gates G1–G5 and page sensing: six rigs (R9–R14) on one 24-bit DAQ and a converted CoreXY printer; CAD with STEP files, drawings and fit checks; DAQ firmware (written, not compiled for the board); USB logger, unit conversion, clock sync, calibration, uncertainty budgets and every analysis, tested on synthetic data (49 self-test checks, 25 tests); offline tablet recorder; bill of materials; 17 experiments (EXP-T01…T17) | executed (design, calculation, synthetic checks) · hardware pending | `docs/measurement_rig.md`, `rig/`, `results/rig/`, `mechanics/cad/rig_*.py` |
| Rev J | Whole-pen closed loop in simulator v2: nose, heel wheel and end-cap together; trackers compared on tuning writers and frozen before the test; results cards per condition; power split; page-sensor error; writer model v2 | executed (simulation) · ET test writers 4–5, the second seed and RL training still to run | `docs/revJ_simulation.md`, `sim2j/`, `results/sim2j/` |
| — | Engineering recommendation: route, conflicting targets with limiting calculations, custom hardware, AI data needs, evidence per benefit | drafted | `docs/recommendation.md` |
| — | Interfaces, decisions, plan with effort ranges (100–174 pw) and quotation list, environment lock | drafted | `docs/icd.md`, `docs/decisions.md`, `docs/plan.md`, `ENVIRONMENT.md`, `requirements.txt` |

## Reproduce

Environment: [`ENVIRONMENT.md`](ENVIRONMENT.md) (Python 3.11 with `requirements.txt`; KiCad 8.0.9; ngspice 42; arm-none-eabi-gcc 13.2; QEMU 8.2).

```bash
python3 -m pip install -r requirements.txt
python3 analysis/audit_recalc.py                    # report recalculation
python3 -m pytest sim/tests -q                      # simulator verification
bash sim/run_all.sh                                 # simulation evidence chain (10-25 min)
python3 mechanics/cad/pen_revA.py --variant A1      # CAD, mass, interference
python3 mechanics/tolerance_analysis.py && python3 mechanics/mass_budget.py
python3 electronics/gen/design_revA.py              # schematic; then kicad-cli ERC/netlist (electronics/README.md)
python3 electronics/calcs/drive_sense.py
(cd electronics/spice && ngspice -b drive_stage.cir && python3 plot_drive_stage.py)
```

Pencil concept:

```bash
python3 mechanics/cad/pencil_revP.py --variant Q      # pencil CAD, fit checks, mass (also --variant L)
python3 analysis/pencil_mechanisms.py                 # forces, mechanisms, power (about 90 s)
python3 -m sim.pencil.run_study                       # pencil model P1 (about 95 s); tests: python3 -m pytest sim/pencil/tests -q
python3 -m sim.pencil.diag_touchdown_tails            # touchdown tails and the tilt-adaptive stop
bash aiguide/run_all.sh                               # AI prediction, guidance and autocorrect (about 15 min)
bash s2r/run_all.sh                                   # sim-to-real twin experiments (about 30 min on 2 processes)
python3 -m sim.handpen.run_study                      # weights, gyroscopes and pivots (about 5 min); tests: python3 -m pytest sim/handpen/tests -q
python3 -m fusion.run_study --workers 2               # accelerometer tracker and AI estimation (tests: python3 -m pytest fusion/tests -q)
python3 -m fusion.viz                                 # 3D replay of the tracker
python3 -m opt.hardware.run_study                     # slim pencil hardware optimisation (P0.2); tests: python3 -m pytest opt/hardware/tests -q
python3 -m opt.tracker.run_study                      # tracker tuned by adjoint and learned trackers (3-4 h on 2 cores); tests: python3 -m pytest opt/tracker/tests -q
python3 -m opt.touchdown.run_study                    # touchdown feed-forward and servo optimisation (about 1.5 h on 2 processes; --quick smoke run); tests: python3 -m pytest opt/touchdown/tests -q
python3 viewer/build.py                               # 3D replay page from the results
```

Rev H (bigger grip):

```bash
python3 -m opt.inertial.run_study                     # nose, tracker, inertial module (about 35 min; --quick about 2 min); tests: python3 -m pytest -q opt/inertial/tests
python3 mechanics/cad/revH_pen.py [--addon]           # Rev H CAD, fit checks, STEP (--addon: with the inertial module)
python3 -m handwriting.run_study                      # before/after writing per condition (--quick smoke run); tests: python3 -m pytest -q handwriting/tests
python3 -m board.run_study                            # guidance board (about 2-3 min); tests: python3 -m pytest -q board/tests
python3 -m aiprior.run_study                          # AI help for severe tremor (about 20 min; --quick about 5 min); tests: python3 -m pytest -q aiprior/tests
python3 -m opt.inertial.front_end --sens              # Rev H front-end closure and its sensitivity check (about 1 min)
python3 mechanics/cad/guidance_board.py               # board CAD and drawing
python3 viewer/explainer/build.py                     # 3-D explainer page from the results
```

Rev J (tip, heel and tail):

```bash
python3 -m drive.run_study                            # heel drive (about 50 min; --quick about 5 min); tests: python3 -m pytest -q drive/tests
python3 -m endcap.run_study                           # end-cap (about 75 min; --quick about 2.5 min); tests: python3 -m pytest -q endcap/tests
python3 nose2/run_study.py                            # nose v2 and autowrite (about 2-3 h; --quick about 1.5 min); tests: python3 -m pytest -q nose2/tests
python3 -m ai2.run_study --workers 1                  # AI and control v2 (about 4 h; --quick about 40 min); tests: python3 -m pytest -q ai2/tests
python3 -m sim2.run_study                             # simulator v2 (about 3 h; --quick); tests: python3 -m pytest -q sim2/tests
python3 -m revj.run                                   # integrated layout, budgets, simulator parameters (about 25 s); tests: python3 -m pytest -q revj/tests
python3 -m bnib.run_study                             # the balanced nib (a few hours in stages; --quick); tests: python3 -m pytest -q bnib/tests
python3 -m revk.run                                   # Rev K integrated layout and budgets (about 15 s; --quick); tests: python3 -m pytest -q revk/tests
python3 mechanics/cad/revK_pen.py --heel             # Rev K CAD, STEP files, drawing and solid checks (about 8 s)
python3 -m wholepen.run_study                         # shifting the whole pen (a few hours in stages; see docs/whole_pen_shift.md §9); tests: python3 -m pytest -q wholepen/tests
python3 -m ai3.run_study                              # spelling, prediction and clarity (several hours; --quick about 8 min); tests: python3 -m pytest -q ai3/tests
python3 -m realtrack.run                              # tremor tracking on real inputs (about 5 CPU h; --quick); tests: python3 -m pytest -q realtrack/tests
python3 -m readable.run                               # the readable target, per-user gates, the gap, reach (about 110 min on 2 workers; --quick about 3 min); tests: python3 -m pytest -q readable/tests
python3 -m nibopt.run                                 # nib optimisation (about 37 min from scratch; --reuse about 3 min; --quick under 1 min); tests: python3 -m pytest -q nibopt/tests
python3 mechanics/cad/nibopt.py --candidate all       # STEP, drawing and summary for each nib candidate (about 24 s)
python3 -m platen.run                                 # moving-paper platen (about 80 min from empty caches; each stage resumes; --quick under 2 min); tests: python3 -m pytest -q platen/tests
python3 mechanics/cad/platen.py                       # platen CAD: STEP, drawing and summary
python3 -m rebaseline.run                             # re-baseline under causal sensing (about 9.7 CPU h, 5 h on 2 jobs: --jobs 2; --quick about 27 min); tests: python3 -m pytest -q rebaseline/tests
python3 results/market/sizing_model.py              # market sizing (study U; arithmetic only, regenerates market_sizing.csv)
python3 results/benchbuild/tools/pipeline_check.py  # bench build: synthetic data through the rig analyses (study H; about 3 s)
python3 -m realdata.run                               # real recorded inputs (downloads the open datasets; about 2.5 h; --quick about 15 min); tests: python3 -m pytest -q realdata/tests
python3 -m sim2j.run_study                            # whole Rev J pen in simulator v2 (several CPU hours; one writer per process: SIM2J_WRITERS=4 ... --stages et); tests: python3 -m pytest -q sim2j/tests
python3 mechanics/cad/revJ_pen.py [--no-endcap]       # Rev J CAD, STEP and drawing
```

Firmware, ML and app have their own build and test commands in their READMEs.

## Repository map

`config/parameters.yaml` holds every parameter with unit, range, status and source (v0.4.4); `config/pencil.yaml` overlays it for the pencil concept (P0.1.2). The directories:

| Directory | Contents |
|---|---|
| `stabpen/` | Shared physics |
| `analysis/` | Audit, EM, thermal, trade |
| `sim/` | Coupled simulator (M1 in `sim/pensim/`, pencil model P1 in `sim/pencil/`) |
| `mechanics/` | CAD, flexures, tolerances, mass |
| `electronics/` | Schematic, calculations, SPICE, BOM |
| `firmware/` | Embedded control core |
| `ml/`, `data/` | Learned predictor pipeline, schemas |
| `app/` | Companion software |
| `aiguide/` | AI prediction, templates and guidance studies (pencil concept) |
| `fusion/` | Sensor models and tremor trackers |
| `opt/` | Optimisation studies: touchdown, tracker, slim hardware, Rev H inertial and front end |
| `handwriting/` | Handwriting outcomes model HW1 and the recording scorer |
| `aiprior/` | AI help for severe tremor: tracker prior, guidance, clean copy |
| `board/` | Guidance board study |
| `drive/` | Rev J heel drive (paper-grounded wheel) study |
| `endcap/` | Rev J inertial end-cap study |
| `nose2/` | Rev J nose v2 and autowrite study |
| `ai2/` | Rev J AI and control v2: trackers, learned estimators, RL, text prediction, style synthesis, shared control |
| `sim2/` | Simulator v2 (MuJoCo) with plug-ins and a Gymnasium environment |
| `revj/` | Rev J integration: layout, budgets, magnetics, simulator parameters |
| `sim2j/` | Rev J whole-pen closed loop in simulator v2 (round 2) |
| `bnib/` | The balanced nib (study B): load-balancing mechanisms, optimisation, simulation, the B1 design |
| `revk/` | The Rev K integrated layout (study K): nib in the pen, counter-face head, tolerances, fit checks, budgets, simulator parameters |
| `wholepen/` | Shifting the whole pen (study W): collar, tails, paper force, write-when-in-reach, closed-loop simulation |
| `ai3/` | Spelling help, prediction and clarity (study S), with the prototype page `ai3/demo/index.html` |
| `realtrack/` | Tremor tracking on real data (study E): estimators, gates, learned networks, the frozen test |
| `readable/` | The readable target (study F): residual sweeps, per-user gates, the prediction/separation split, reach |
| `nibopt/` | The balanced-nib optimisation (study N): matched model, reconciliation, guide screen, NSGA-II search, candidates, budgets |
| `platen/` | The moving-paper platen (study P): moving-page plant on HW1, camera predictor, tremor, accepted writing, sensitivity, concept calculations |
| `rebaseline/` | The re-baseline (study X): impact register, causal reruns of sim2j's cards, the balanced nib in sim2, reach with B1's dynamics, page model v2 on real inputs |
| `results/market/` | Users and market (study U): sizing model and CSV, competitors, interview guides, survey, go/no-go criteria |
| `results/benchbuild/` | The first bench build (study H): parts lists, costs and schedule, test-to-decision map, data templates, tools |
| `realdata/` | Real recorded data library (study R): handwriting and tremor sets, severity classes, page-sensor error model, reader, HW1 runs on real inputs |
| `rig/` | Measurement rigs (study M): DAQ frame protocol, logger, analyses, self-test, Teensy firmware, tablet recorder |
| `s2r/` | Sim-to-real: virtual bench, identification, calibrated twin |
| `viewer/` | 3D replay page; `viewer/explainer/` the 3-D explainer (Rev J) |
| `validation/` | Experiments and studies |
| `docs/` | Everything written |
| `results/` | Generated outputs with provenance |

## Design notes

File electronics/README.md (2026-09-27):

# Research electronics, Rev A

**Evidence status: PROPOSED DESIGN.** Nothing in this directory has been built or measured.

| Check | Status |
|---|---|
| Schematic | Generated and checked by software |
| Calculations | Analytical |
| Drive stage | Simulated in ngspice with idealised switches |
| Placement | Area-feasibility calculation only |

Every part carrying a `VERIFY` or `SELECT` note in [`bom_revA.csv`](bom_revA.csv) must be checked against its datasheet or reference design before layout. The note gives the specific item to check.

## What is here

| Path | Content | How it is checked |
|---|---|---|
| `gen/design_revA.py` | Declarative circuit specification: 11 sheets, 148 placements | — |
| `gen/kicad_gen.py`, `gen/sexpr.py` | Generator that writes editable KiCad 8 schematics from the specification. Symbols are copied from the installed KiCad 8 libraries, so pin numbers come from maintained library data | — |
| `kicad/` | `pen_research.kicad_pro` / `.kicad_sch`, one sheet per function, `sym-lib-table` and `fp-lib-table` | `kicad-cli sch erc`: 0 errors, 1 accepted warning (below) |
| `kicad/pen_research.net` | KiCad's own netlist export | `gen/check_netlist.py` against `intended_netlist.json`: **PASS**, 102 nets, 492 pins |
| `kicad/pen_research_revA.pdf` | Plotted schematic, 12 pages | — |
| `bom_revA.csv` | BOM generated by `gen/make_bom.py`: 79 lines, 148 placements | 45 VERIFY, 3 SELECT, 26 generic passives, 5 fully specified |
| `calcs/drive_sense.py` | Coil winding vs supply, current-sense chain, PWM ripple, current-loop bandwidth, timing, power | → `results/electronics/drive_sense.json`, figures |
| `spice/drive_stage.cir`, `spice/plot_drive_stage.py` | ngspice transient: H-bridge, shunt, INA241, anti-alias, window comparator, latch and load switch, including a coil short | → `results/electronics/spice_drive_stage.json`, `fig_spice_drive_stage.png` |
| `gen/placement_study.py` | Board area and height feasibility from library courtyards and the CAD envelope | → `results/electronics/placement_study.json`, `fig_placement_study.png` |

Regenerate everything. UUIDs are deterministic (uuid5 of the sheet and item order), so regenerating an unchanged design reproduces the schematic files and a real change shows as a small diff:

```bash
python3 electronics/gen/design_revA.py
cd electronics/kicad
kicad-cli sch erc --format report --severity-all -o erc_report.rpt pen_research.kicad_sch
kicad-cli sch export netlist --format kicadsexpr -o pen_research.net pen_research.kicad_sch
python3 ../gen/check_netlist.py
kicad-cli sch export pdf -o pen_research_revA.pdf pen_research.kicad_sch
cd ../..
python3 electronics/gen/make_bom.py
python3 electronics/gen/placement_study.py
python3 electronics/calcs/drive_sense.py
cd electronics/spice && ngspice -b drive_stage.cir && python3 plot_drive_stage.py
```

Dependency: KiCad 8.0 (tested with 8.0.9, libraries version 20231120). Also ngspice 42 and Python 3.11 with numpy, scipy and matplotlib.

**Accepted ERC warning.** The IMU's unused auxiliary SPI pins `SDx`/`SCx` connect to GND, as the LSM6DS-family datasheets recommend for unused pins. ERC flags this as a power-output-to-bidirectional connection. Pin functions for the LSM6DSV16X are marked VERIFY.

## Architecture

```mermaid
flowchart LR
  USB[USB-C tail board<br/>ESD, CC] --> CHG[MCP73831<br/>147 mA]
  CHG --> CELL[LiPo ~200 mAh<br/>>= 5 C]
  CELL --> PROT[BQ29700 + 2 NMOS]
  PROT --> LDO[TLV75530<br/>+3V0 / +3V0A]
  PROT --> LS[TPS22917<br/>VMOT]
  LDO --> MCU[nRF5340<br/>LDO-only mode]
  LS --> HBX[DRV8212P X] & HBY[DRV8212P Y]
  HBX --> SX[0.1 ohm + INA241A1] --> COILX[coil X 6 ohm]
  HBY --> SY[0.1 ohm + INA241A1] --> COILY[coil Y 6 ohm]
  SX & SY --> ADC[SAADC diff vs VREF 1.25 V]
  SX & SY --> WIN[4x comparator window +/-0.8 A]
  WIN --> LATCH[74AUP1G74 latch] --> AND[74LVC1G11<br/>ACT_EN = REQ.FAULT_N.NOCHG]
  AND --> LS
  MCU --- HALL[TMAG5170<br/>q1, q2, axial slide]
  MCU --- OPT[3 optical modules]
  MCU --- IMU[LSM6DSV16X]
  MCU --- FLASH[QSPI 16 MB]
```

| Sheet | Function |
|---|---|
| `power_charge` | USB-C receptacle, USBLC6 ESD, CC pull-downs, MCP73831 charger, VBUS/2 detect |
| `battery_supply` | Cell pads, BQ29700 protector with charge/discharge FETs, TLV75530 LDO with a filtered analogue rail, TPS22917 actuator load switch, VBAT divider, REF3012 1.25 V reference |
| `mcu` | nRF5340-QKAA with DEC decoupling, 32 MHz and 32.768 kHz crystals, RF match, antenna pi-pad and chip antenna, Tag-Connect SWD, SPI series termination, isolated ADC reference input |
| `sensing` | IMU, three optical-module flex connectors, coil NTC |
| `force` | DNP: ADS1220 and strain-bridge input for bench reference measurements |
| `stage_position` | TMAG5170 3-axis Hall on the tail flex; DNP analogue Hall alternative |
| `actuator_x`, `actuator_y` | DRV8212P, 0.1 Ω shunt, INA241A1, 1 kΩ/10 nF anti-alias filter, two comparators per axis, coil pads |
| `storage_comm` | QSPI flash, UART pads |
| `user_interface` | Button, LED, ERM driver, test points |
| `fault_handling` | Over-current latch, charging interlock, 3-input enable gate, trip thresholds |

## Decisions carried by the circuit

- **DEC-012: coil wound to 6 Ω (was 11 Ω).**
  - Holding power (F/(n·K_m))² does not depend on the winding. The voltage needed does: V = F/(n·K_m·√R)·(aR + R_ext).
  - With the 11 Ω winding, at VBAT = 3.3 V and an 85 °C coil, 3.7 % of the thermally allowed envelope is voltage-limited.
  - 6 Ω was chosen as the largest winding with none voltage-limited under that check.
  - **Revisited in v0.4.3 (firmware review D11).** The check now puts each envelope point at its own steady coil and magnet temperature (coil up to its 120 °C limit), includes the magnets' Br tempco and adds the dynamic correction force. At 3.3 V, 6 Ω then cannot hold the static load at 0.5 % of the thermally allowed envelope (the hot, high-force corner; up to 8.7 % short of voltage), and 1.2 % with a typical correction (9 Hz, 0.3 mm). 4 Ω holds everywhere with ≥ 8 % margin, at 22 % more current and higher ripple. 6 Ω stays the baseline until EXP-B03 winds both. In the corner, the headroom fault (duty > 0.95 for > 50 ms) and the low-battery derate act (`drive_sense.json` `winding_assessment`, `fig_headroom.png`).
  - Consequences: K_f = 0.717 N/A (after the 0.50 mm gap of DEC-007 rev.), L ≈ 175 µH (air-core estimate scaled by turns²), design-point hold current 0.335 A, bridge and shunt loss 7.7 % of copper loss.
- **40 kHz centre-aligned PWM, 200 duty levels.**
  - At 20 kHz the 6 Ω coil's ripple is 159–239 mA p-p and loop delay limits the current loop to about 1.3 kHz.
  - At 40 kHz the ripple is 83–129 mA p-p, and the loop delay allows a crossover of up to 2.3 kHz at 50° phase margin. The implemented loop crosses at 2 kHz with 55.8° margin, as in the simulator and firmware (Kp 2.20 V/A, Ki 81.9 kV/(A·s)).
  - The force ripple at 40 kHz moves the stage by less than 1 nm.
- **In-line shunt with INA241A1.**
  - The INA241 tolerates PWM common-mode swings. The chain gives 1.0 V/A about 1.25 V, a ±1.2 A linear range and 0.59 mA per ADC LSB.
  - Noise is about 0.55 mA RMS per sample and is ADC-dominated.
  - Offset is calibrated at every pen-up with the bridge in coast.
- **Sampling.** ngspice shows that sampling only at the PWM-period centre biases the current reading by −11 mA (−3.4 %) after the anti-alias RC at duty 0.72. The firmware samples at both counter extremes and averages: 2 axes × 2 × 40 kHz = 160 kS/s, SAADC limit VERIFY. The remaining duty-dependent error goes into a `CAL_ISNS` table (docs/icd.md §3).
- **nRF5340 in LDO-only, normal-voltage mode.** DCC, DCCD and DCCH are left open, so there is no DC/DC switching next to the Hall and sense front ends. The few-mA LDO penalty is small against 0.2–0.8 W of actuator load. DEC-pin capacitor values are marked VERIFY: the Nordic reference circuitry could not be retrieved in this session.
- **Hardware interlock, independent of firmware.** ACT_EN = ACT_EN_REQ AND FAULT_N AND NOCHG.
  - Any window-comparator trip latches FAULT_N low and opens VMOT.
  - VBUS presence blocks actuation.
  - An MCU reset releases ACT_EN_REQ through a 100 kΩ pull-down.
  - In ngspice, a coil short is detected in **8.8 µs** and VMOT opens at **22.6 µs**. The load switch is modelled as a 20 µs first-order turn-off (VERIFY). The fault peak is 5.4 A with ideal switches; the DRV8212P's internal over-current protection (VERIFY) would clamp it earlier.
- **One 3-axis Hall sensor for stage and force.** The TMAG5170 reads a sense magnet on the lever tail. Bx and By give the stage angles; Bz gives the axial slide s, and F_ax = F_pre + k_ax·s. The strain-bridge ADC is DNP and kept only as a bench reference.

## Budgets (calculation)

| Quantity | Value | Source |
|---|---|---|
| Electronics supply current (typical, excl. actuator) | 31 mA (115 mW at 3.7 V); optics are a 15 mA placeholder | `drive_sense.json` |
| Actuator copper loss in contact, design point (θ 50°, N 1 N) | ≈ 0.50 W referenced to 20 °C, ≈ 0.65 W at the 96.6 °C design coil (direction-averaged) | `results/trade/config_trade.json`; `drive_sense.py` |
| Allowable average copper loss (moving coil) | 0.412 W, set by the 120 °C coil limit (0.50 mm air gaps, 115 mW electronics) | `results/thermal/thermal.json` (v0.4.4) |
| Share of the writing envelope within that limit | 70 % (θ 35–75°, N 0.2–2 N log-uniform, μ 0.05–0.35; continuous contact) | `drive_sense.json` |
| Runtime at the design point, 200 mAh × 0.8 usable | 54 min of continuous contact; 81 min of writing at 65 % pen-down duty (`results/trade/config_trade.json`). A cell that fits the Rev A.1 bay may hold only ~130 mAh (DEC-014) | this README |
| Stage-period CPU and bus occupancy (500 µs) | CPU ≈ 130 µs, SAADC ≈ 210 µs, SPIM4 ≈ 50 µs, SPIB ≈ 16 µs | `fig_stage_timeline.png`; to be replaced by logic-analyser captures |

The nominal design point sits at the moving-coil thermal limit. This is the audit's conclusion (COR-02) seen from the electronics side: Rev A is a research instrument, and the skid or bias variants (DEC-008) remain the product path.

## Packaging finding (placement study)

The courtyard area of the main-board parts is **779 mm²**. Two sides of the 29 × 11.5 mm board in the CAD, less the antenna keep-out, give **517 mm²**. **The Rev A circuit as drawn does not fit the Rev A mechanical envelope.** Three parts also exceed the 1.2 mm component-height envelope:

- the button (1.9 mm);
- the SOT-23-5/6 LDO and load switch (1.45 mm);
- the SOT-23-5 charger (1.45 mm).

The "Rev A.1 package plan" in `placement_study.py` makes these changes:

- one 10-pin nose flex instead of three optical connectors;
- X2SON comparators and LDO;
- USON flash;
- 0201 passives below 1 µF;
- a WLCSP-class dual MOSFET;
- charger moved to the USB tail board.

That plan cuts the area to 506 mm². It fits only if the board grows to **41 mm**, which requires the 44 mm 10440 bay to become a ~32 mm pouch cell. Courtyard density is then 0.65, so HDI is required (via-in-pad under the aQFN94, 6–8 layers). The button and load switch still need a thinner part or a local wall relief.

These substitutions change symbols and pin maps, so they are **not yet applied** to the schematic. Each is a VERIFY or SELECT item, tracked as open issue E-1.

## MCU pin plan (nRF5340-QKAA)

| Function | Pins | Notes |
|---|---|---|
| Current sense | AIN0 = ISNS_X, AIN1 = ISNS_Y, AIN4 = VREF_ADC | Differential against AIN4 |
| Monitoring | AIN2 = VBAT/2, AIN3 = NTC | Ratiometric NTC |
| Analogue Hall option | AIN5/AIN6 (DNP DRV5055) | — |
| Spare | AIN7 | Test point |
| High-speed SPI (SPIM4) | P0.08 SCK, P0.09 MOSI, P0.10 MISO, P0.11 HALL_CS_N, P0.12 OPT1_CS_N | 33 Ω series termination |
| Other optics | P0.29/P0.30 CS, P0.31 IRQ | — |
| QSPI flash | P0.13–P0.18 | — |
| Bridges | P0.19–P0.22 IN1/IN2 X/Y, P0.23 DRV_SLEEP_N, P0.24 ACT_EN_REQ | — |
| SPIB (IMU, ADC option) | P1.02–P1.04 | IMU CS P1.01, INT1/INT2 P1.00/P1.15 |
| Bench ADC option | ADC_DRDY_N P0.02, ADC_CS_N P0.03 | NFC pins: set UICR.NFCPINS to GPIO |
| UART | P1.05/P1.06 | Pads |
| Fault and interlock | P1.07 FAULT_N, P1.12 FAULT_CLR_N, P1.14 CHG_DET | — |
| UI | P1.08 button, P1.09 LED, P1.11 haptic | — |
| Status inputs | P1.10 CHG_STAT, P1.13 HALL_ALERT_N | — |

## Board-to-board connections

| Link | Signals | Current | Form |
|---|---|---|---|
| Main ↔ nose flex (optics) | +3V0, GND, SCK, MOSI, MISO, 3× CS, IRQ | < 50 mA | 0.5 mm FPC, ~60 mm; SI check at SPI clock |
| Main ↔ tail flex (Hall) | +3V0A, GND, SPIA ×3, HALL_CS_N, HALL_ALERT_N | < 5 mA | Solder or hot-bar flex |
| Main ↔ actuator coils | COIL_X_P/OUT2_X, COIL_Y_P/OUT2_Y, NTC ×2 | ≤ 0.8 A per coil | Flying leads to pads; strain relief on the moving coil is an EXP-B03 item |
| Main ↔ cell | VBAT, CELL_NEG | ≤ 1.2 A peak | Pads |
| Main ↔ USB tail board | VBUS, D+, D−, GND (+ charger if Rev A.1) | 0.5 A | Flex along the cell |

## Bring-up procedure (bench, before any closed-loop test)

The steps below are measurements still to be made; nothing here has been measured yet. Record every result in `validation/records/` with the board serial.

| Step | Action | Pass criterion |
|---|---|---|
| 1 | Visual and X-ray inspection of the aQFN94 and WSON parts; ohmmeter checks VBAT–GND, VMOT–GND, +3V0–GND | No shorts (> 1 kΩ) |
| 2 | Bench supply on VBAT, 3.7 V with 50 mA limit, pads unloaded | +3V0 = 3.00 V ± 1.5 %; +3V0A same; VREF_1V25 = 1.250 V ± 0.2 %; supply current < 15 mA before firmware |
| 3 | SWD connect and erase; flash a blink-and-clock test | HFXO starts; 32 MHz within ±40 ppm (frequency counter on a GPIO clock output); LFXO runs |
| 4 | SPI ID reads: TMAG5170, LSM6DSV16X, flash JEDEC ID, optical modules | All IDs correct at 1, 8 and 32 MHz (SPIM4); scope SCK at the nose connector (ringing < 20 % of swing) |
| 5 | Current-sense offset with bridges asleep | ISNS_X − VREF within ±3 mV; noise ≤ 1 mA RMS equivalent |
| 6 | Dummy load (6.8 Ω + 180 µH) on each coil output; 40 kHz PWM at duties 0.1–0.9 | ISNS vs a 0.1 %-class current probe: gain error ≤ 1 % after `CAL_ISNS`; ripple matches `fig_pwm_ripple.png` within 25 % |
| 7 | Timing: toggle GPIOs at ISR and task entry and exit; logic analyser | 40 kHz ISR ≤ 5 µs; 2 kHz task ≤ 250 µs; jitter ≤ 20 µs |
| 8 | Protection: step the dummy load to 0.2 Ω with the lab supply current-limited to 2 A | FAULT_N latches; VMOT < 0.5 V within 50 µs; recovery only via the clear sequence with ACT_EN_REQ low |
| 9 | Interlocks: plug USB during PWM | ACT_EN low within 1 ms; no actuation while charging |
| 10 | Watchdog: halt the core under the debugger during PWM | Reset releases ACT_EN_REQ; VMOT off |
| 11 | Charger: 147 mA CC into a 200 mAh cell at 25 °C; skin-temperature probe on the barrel | Termination at 4.20 V ± 0.75 %; barrel < 41 °C |
| 12 | Hall calibration jig (EXP-B04) and actuator force map (EXP-B03) | Produces `CAL_HALL` and `CAL_ACT` |

## Open issues

1. **E-1** Packaging: apply the Rev A.1 package plan (new symbols and pin maps), then lay out. Decide between the 41 mm board with a pouch cell and a two-board split.
2. **E-2** nRF5340 DEC-pin capacitor values, RF matching and antenna keep-out against Nordic's reference circuitry and a VNA measurement on the assembled pen.
3. **E-3** LSM6DSV16X pin functions on the LSM6DS-family placeholder symbol.
4. **E-4** TMAG5170 range variant from the sense-magnet field map; field crosstalk from the actuator at 40 kHz (sample mid-PWM).
5. **E-5** INA241A1 common-mode transient recovery at 40 kHz edges with 3.0–4.2 V VMOT; the ngspice model is behavioural.
6. **E-6** SAADC aggregate sample rate for dual-extreme sampling (160 kS/s).
7. **E-7** Optical module selection (EXP-S01) sets the nose-flex interface and its supply current.
8. **E-8** Thermal: the design point sits at the moving-coil copper-loss limit (see Budgets).

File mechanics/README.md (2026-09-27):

# Mechanics and packaging

**Evidence status:**

- **Proposed design:** CAD concept at nominal geometry.
- **Calculation:** flexures, tolerances, mass, trade study, thermal network.
- **Simulation:** field models, coupled dynamics.

No part has been made or measured. Measured values replace these rows in EXP-B03, B05, M02 and M03 (`validation/bench_protocols.md`).

## Architecture (Rev A baseline, configuration B)

- **Nib carrier.** The refill is carried in a titanium carrier tube. The tube pivots about a virtual centre on the axis **L1 = 12 mm** behind the ball (DEC-003).
- **Axial suspension (DEC-007, revised).** The refill slides inside the carrier on a spiral-arm diaphragm suspension (k_ax ≈ 2 kN/m, DEC-006), so the carrier and coil paddle do **not** slide axially (κ_s = 1).
  - The lever arm changes with the slide, L1 − s. The controller compensates this from the measured slide.
  - Rejected layout: the whole lever sliding (κ_s = 0) consumes the actuator's axial gap (see Tolerances).
- **Actuator.** A rear annular sandwich Lorentz actuator, 38 mm behind the pivot (n = L2/L1 = 3.17). A moving-coil paddle on the carrier sits between two fixed quadrant-magnet rings with back iron. Each side has a 0.50 mm axial gap (Rev A.1).
- **Stage and force sensing.** A sense magnet on the refill's rear plug is read by a 3-axis Hall sensor on a tail flex. The x/y channels give the lever angle; z gives the axial slide and hence the writing force.
- **Optics.** Three chip-scale optical modules sit in the nose flanks at 30/150/270°, so one faces the page at any roll angle.
- **Envelope.** Barrel Ø15 mm, with a local Ø16 mm bulge over the actuator; length 150 mm.

## Files

| Path | What it does | Output |
|---|---|---|
| `cad/bench_rig.py` | Stage-A loaded bench mechanism (pen-scale nib, lever and gimbal; two commercial VCMs; hand-simulant disturbance stage; goniometer; dead-weight normal force; F/T-sensed platen on an XY stage) with platen-clearance check | `results/cad/bench_rig_*`, `drawing_bench_rig.png` |
| `cad/pen_revA.py` | Parametric CadQuery model with swept-workspace interference check at full tip travel in 12 directions, fixed-vs-fixed check, and mass/CoM table. `--variant A1` applies the Rev A.1 packaging and tolerance changes | `results/cad/pen_revA*_summary.json`, STEP assembly and parts |
| `drawings/make_drawings.py` | Section and cross-section drawings from the model | `results/cad/drawing_revA_*.png/svg` |
| `flexure_calc.py` | Wire-pivot candidates (all fail on stress or buckling), cross-strip gimbal, spiral-arm diaphragm | `results/mechanics/flexure_calc.json` |
| `tolerance_analysis.py` | Clearance stacks S1–S5: worst case, RSS and Monte Carlo | `results/mechanics/tolerance.json`, `fig_gap_budget.png` |
| `mass_budget.py` | CAD masses plus allowances plus 10 % contingency for Rev A, A.1, and A.1 with a polymer rear barrel | `mass_budget.csv`, `results/mechanics/mass_budget.json` |
| `../analysis/config_trade.py` | Configurations A–F at design/high/bench-corner loads | `results/trade/config_trade.json` |
| `../analysis/em_actuator.py`, `em_planar.py` | magpylib field models of the actuator candidates | `results/em/*.json` |
| `../analysis/thermal.py` | Lumped thermal network | `results/thermal/thermal.json` |

Regenerate:

```bash
python3 mechanics/cad/pen_revA.py
python3 mechanics/cad/pen_revA.py --variant A1
python3 mechanics/flexure_calc.py
python3 mechanics/tolerance_analysis.py
python3 mechanics/mass_budget.py
```

Dependencies: CadQuery 2.8, magpylib 5.2, numpy, scipy, matplotlib.

## Key numbers (calculation unless stated)

| Quantity | Rev A | Rev A.1 | Source |
|---|---|---|---|
| Modelled mass (solids × density) | 31.6 g | 28.5 g | CAD |
| Mass with allowances + 10 % contingency | 40.7 g | 37.2 g; **33.2 g** with polymer rear barrel | `mass_budget.json` (REQ-FORM-003 ≤ 35 g) |
| Centre of mass from the tip | 80.6 mm | 79.4 mm; **76.0 mm** with polymer rear barrel | REQ-FORM-004 ≤ 70 mm: **still violated** |
| Moving mass / tip-equivalent inertia | 1.93 g / **13.4 g** | 1.96 g / **13.7 g** | CAD distributed-mass integration (the earlier 10.3 g point-mass figure understated it); REQ-MECH-003 ≤ 12 g **violated**. The simulator already uses 13.7 g |
| Mechanical tip travel / lever tilt | 0.65 mm / 3.11° | 0.60 mm / 2.87° | tolerance analysis |
| Pivot stiffness at the tip | cross-strip gimbal 75.8 N/m; stress 177/82 MPa (full travel / typical); buckling margin 19 | same | `flexure_calc.json` |
| Axial suspension | spiral-arm diaphragm 1984 N/m, 231 MPa at the 0.6 mm stop | same | `flexure_calc.json` |
| Holding power at the design point (θ 50°, N 1 N) | 0.50 W in contact (referenced to 20 °C); coil ≈ 97 °C at 65 % pen-down | +6 % for the wider gap; the wider gap also raises the coil-to-structure resistance to 145 K/W | trade, thermal, tolerance |
| Interferences at full travel (nominal geometry) | none | none | CAD check |

Model inconsistency: the CAD still models the pivot with three inclined wires. The flexure analysis replaced them with a cross-strip gimbal at the same virtual centre. The mass difference (~0.1 g) is carried as an allowance; the gimbal geometry is a CAD to-do (M-3).

## Tolerances

`tolerance_analysis.py` uses the nominal CAD geometry. Tolerances are assumed at ±3σ for ground or bonded precision parts; each is listed with its basis in the JSON.

| Stack | Rev A nominal | Rev A.1 (gap 0.50, travel 0.60, κ_s = 1) | Consequence |
|---|---|---|---|
| S1 paddle–magnet, front face (tilt) | RSS +14 µm (worst −185 µm) | RSS **+93 µm** (worst −106 µm) | Gap 0.45 → 0.50 mm costs about 2.9 % of K_f (6 % power) |
| S1 rear face, whole lever slides (κ_s = 0) | contact probability 0.97 at design load, 1.0 at the axial stop | 0.56 / 1.0 | κ_s = 0 **rejected** (DEC-007 rev.) |
| S1 rear face, refill slides (κ_s = 1) | RSS +125 µm | RSS **+188 µm** | — |
| S2 carrier through magnet bore at full swing | RSS +16 µm | RSS **+174 µm** | Travel limited to 0.60 mm (control limit 0.55 mm) |
| S3 ball/cone in 3.6 mm aperture | RSS +0.48 mm | +0.53 mm | Not critical |
| S4 lever-ratio gain | ±0.87 % RSS | same | Calibrated out (EXP-B04) |
| S5 Hall sense-magnet distance vs refill length (±0.3 mm, VERIFY ISO class) | field ×0.65 … ×1.65 | same | Firmware re-zeroes the force channel at every refill insertion |
| S6 nose-to-paper clearance, worst stage position | **−2.1 mm at 35°, −1.2 mm at 50°: the nose touches the paper** (tip Ø6 mm, 1 mm behind the ball) | +0.60 / +2.1 / +4.4 mm at 35 / 50 / 75° (tip Ø5.2 mm, 5 mm behind the ball, aperture 4.2 mm) | The refill point must protrude about 5 mm, as on an ordinary ballpoint; the optics at z 14.2 mm still fit inside the nose (CAD check) |

Simulation of the κ_s choice (`sim/diag_kappa.py`, `results/sim/kappa_compare.json`) shows κ_s = 1 with compensation matches κ_s = 0. Device distortion is 59–61 µm in both. The oracle ratio is 0.27 vs 0.31 at 35° and 0.127 vs 0.131 at 50°.

## Bench rig concept (prototype stage A)

The rig tests the physics (EXP-B01, B03, B05, B06, B08, B09) before the miniature pen exists. It has a dimensioned parametric CAD: `cad/bench_rig.py` → `results/cad/bench_rig_assembly.step`, `bench_rig_summary.json`, `drawing_bench_rig.png`. The model checks that the module clears the platen from 35° to 75°. That check forced the module to adopt the pen's slim nose, with the wide VCM frame starting 40 mm up the axis.

1. **Nib and lever module at pen scale, oversized actuation.**
   - A real D1 refill in a titanium carrier on a cross-strip gimbal, L1 = 12 mm.
   - Driven through the same 3.17:1 lever by two commercial 12.7 mm moving-coil VCMs (Moticont LVCM-013 class, K_m ≈ 0.8 N/√W; AMF-02), in place of the custom annular actuator.
   - This removes actuator risk from the first cancellation experiments. EXP-B03 then qualifies the custom actuator separately.
2. **Housing held by a hand simulant or a real hand.**
   - The rig housing is either (a) mounted on a 2-axis voice-coil shaker that injects recorded or synthetic tremor with a two-stage impedance matching HAP-26, or (b) held by participants for the EXP-B06 grip identification.
3. **Page and reference metrology.**
   - Paper on a 6-axis force/torque sensor (Nano17 class, ~3 mN resolution) on a motorised XY stage for the writing motion. A goniometer sets θ from 35° to 75° and φ.
   - Housing motion by laser triangulation (µm class, ≥ 10 kHz).
   - Deposited ink scanned at ≥ 2400 dpi (10.6 µm per pixel) for the ink-error metrics defined in `docs/physics.md` §8.
4. **Electronics.** Rev A drive, sense and interlock circuit (`electronics/`) on a bench-size board, streaming research frames over USB (`docs/icd.md` §4.2). Timing and fault behaviour are therefore exercised on the real control path.

Prototype stage B (the tethered research pen) starts only after stage A shows these results:

- loaded cancellation at practical force (EXP-B09 gate);
- ink tolerance to the resulting force modulation (EXP-B08).

## Open issues

- **M-1.** The centre of mass is 76 mm even with a polymer rear barrel, against ≤ 70 mm. The requirement itself is provisional: compare with ordinary pens in EXP-M03 and H02. Options: 140 mm length, lighter stator (reduced back iron, at a K_m cost), cell moved forward of the PCB (then RF moves).
- **M-2.** Rev A.1 needs a 41 mm PCB and a ~32 mm pouch cell (DEC-014). Obtain a supplier drawing for a 5 × 12 × 32 mm cell rated ≥ 5 C.
- **M-3.** Replace the wire pivots with the cross-strip gimbal in the CAD; model the diaphragm; model the three optical windows.
- **M-4.** Moving-coil leads cross the pivot: flex-life of the coil leads over 10⁷ tremor cycles (EXP-M02, B10).
- **M-6.** Tip-equivalent inertia is 13.7 g, above the ≤ 12 g requirement. A CFRP carrier tube (1.55 g/cm³ against titanium's 4.43 g/cm³) would bring it to about 9.5 g (calculation). The price is stiffness and bond-joint risk at the gimbal and paddle.
- **M-5.** The thermal path from a moving coil in an air gap (≈ 145 K/W to the magnets and iron, 157 K/W to ambient at steady state) sets the holding-power limit. Measure it early (EXP-B03 coupon, EXP-B07).

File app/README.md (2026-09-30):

# penapp: companion-app reference implementation (research pen Rev A)

**Status.** Reference implementation, version 0.1.0, against ICD section 4 (`docs/icd.md`, `format_version` 1). ICD v1.1 changed only section 5 (the ML contract); section 4 is unchanged from v1.0, and "ICD 1.0" in stored objects refers to that format.
**Evidence status.** Every dataset used or produced here is **synthetic**. The sources are glyph handwriting of known text and coupled-simulator traces (`results/sim/nominal/traces_*.npz`). No person was recorded and nothing was measured. The assistant is not a medical device.

The app implements the two principles the audit retained from the source report (`docs/audit.md`):

- local correction is kept separate from page capture;
- the immutable original strokes are kept separate from derived layers, and language models serve only as note tools.

## Quick start

```bash
# from the repository root; Python 3.11, numpy, jsonschema (+ scipy for synthesis; numba optional, faster)
python3 app/demo.py                    # full synthetic demo -> data/samples/, results/app/ (~30 s)
python3 -m pytest app/tests -q         # 137 tests (see "Tests")

export PYTHONPATH=app PENAPP_STORE=/tmp/penstore
python3 -m penapp import data/samples/demo_text_errands.penlog     # uses <log>.truth.json if present
python3 -m penapp search library
python3 -m penapp ask "When should I return the library books?"
python3 -m penapp render <note_id> -o note.svg --overlay text --force-width
python3 -m penapp fidelity             # -> results/app/capture_fidelity.json
python3 -m penapp list | verify | edit <note_id> <span_id> "<text>"
```

No code path in the tests, the demo or the CLI makes a network call.

## Review and accept spelling suggestions

The 30 September engineering update adds an explicit proposal/acceptance path.
Supply a local UTF-8 training corpus, one sentence per line, then inspect the
offered span IDs and before/after text in the JSON output:

```bash
export PYTHONPATH=app PENAPP_STORE=/tmp/penstore
python3 -m penapp propose-corrections <note_id> --corpus sentences.txt --out proposal.json
python3 -m penapp accept-corrections proposal.json --span-id <offered_span_id>
```

Repeat `--span-id` for additional choices. Generating a proposal leaves the note
unchanged and refuses to overwrite an existing proposal file. Acceptance records
only selected changes as `user_edit` and refreshes search. The captured ink and
literal recognition remain intact. Changed note text or a tampered proposal
invalidates acceptance; generate and review a fresh proposal instead. Existing
user-edited spans are protected. This workflow changes digital text; physical
future-stroke execution uses the separate `ai3.accepted_completion` planner.

The CLI uses a local word/character ngram research model and makes no corpus
download. Its scores are not calibrated probabilities of writer intention or
validated dyslexia outcomes. Known words are protected by default; the explicit
`--allow-known-word-changes` option enables that additional research behavior.
`--personal-word` adds vocabulary and can be repeated. The proposal records the
corpus hash, assumed recognition-error rate and score threshold. The historical
`autocorrect_note` evaluation API remains available for reproducing older studies;
new interactive work should use proposal and explicit acceptance.

Training text is normalized through the existing lowercase ASCII corpus
normalizer (including accent folding and punctuation mappings); the proposal
records both raw and normalized corpus hashes. This does not establish
multilingual support. Note tokens outside the model alphabet are kept exactly
as written. Keep the proposal JSON for the model/corpus audit trail: the accepted
note layer records the user edit, while training provenance remains in that
proposal. Its digest detects changed local proposal content, not authenticated
approval by a remote service or another person.

## Architecture

```
 pen (firmware)                               app (this package, local-first)
 ------------------                           -------------------------------------------------------
 2 kHz research frames 0x01 --USB--+
 200 Hz stroke samples 0x02 --BLE--+--> logfmt.read_log  CRC-16 per record, resync, time unwrap
 events 0x03, cal 0x04, notes 0x05-+          |
                                              v
                                   notes.NoteStore (directory of JSON, schema-validated)
                                     originals/<sha256>.json  immutable ORIGINAL layer (0444)
                                     notes/<note_id>.json     session manifest (header, events, parse report)
                                     layers/<layer_id>.json   DERIVED layers, append-only (0444)
                                       segmentation        capture.py   pen-down/up strokes, lines, words
                                       hand_path_estimate  capture.py   p_H from research frames
                                       recognition         recognize.py null | ground truth | inject errors | ML Kit spec
                                       user_edit           notes.py     corrections, keep stroke links
                                       ai_summary          grounded.py  cited answers only
                                              |
                  render.py (SVG) <-----------+-----------> search.py (SQLite FTS5, rebuildable cache)
                                                                  |
                                                     grounded.py retrieval -> LLMClient -> validator
```

| Module | Role |
|---|---|
| `logfmt.py` | ICD section 4 writer and reader. It handles the header, records, CRC-16/CCITT-FALSE, the fixed payloads 0x01, 0x02 and 0x03, the firmware-proposed payloads 0x04 and 0x05, byte-wise resynchronisation and timestamp unwrapping. |
| `notes.py` | Note store: content-addressed original layer, derived layers with provenance, schema validation, integrity checks, user edits, export bundle and erasure. |
| `capture.py` | Stroke table (pen-down/up), line and word grouping, hand-path layer, resampling, exact discrete Fréchet distance and the capture-fidelity analysis. |
| `render.py` | Deterministic SVG. Options: force-to-width, overlays of any derived layer, highlighting of cited strokes. |
| `recognize.py` | `Recognizer` protocol, null / ground-truth / error-injection implementations, CER/WER, and the ML Kit adapter specification. |
| `search.py` | FTS5 index over the effective text. Each hit gives matched words with stroke-id ranges and page boxes. |
| `grounded.py` | Retrieval, the `LLMClient` protocol, a deterministic local extractive default, per-sentence citation validation, refusals and storage as `ai_summary`. |
| `synth.py`, `vectors.py` | Synthetic sessions (glyph polylines timed with `stabpen.signals.PathBuilder` and `stabpen.signals.tremor`; simulator traces) and the ICD example vector. |
| `cli.py`, `__main__.py` | `python -m penapp import|render|search|ask|fidelity|list|verify|edit`. |

## Data model

### Original layer (ICD section 4.5)

- **Content.** The stroke samples (0x02) exactly as logged. In JSON this is `columns = [t_ms, stroke_id, x_um, y_um, force_mN, theta_raw, phi_raw]` with one integer row per sample, in raw logged units.
- **Address.** `sha256` over the concatenated 20-byte ICD 0x02 payloads (little-endian) in log order. This is the exact byte string in the log, so anyone can recompute it from the `.penlog` file. The test `test_content_address_is_sha256_of_logged_payloads` does so independently.
- **Immutability, enforced at every level:**
  - `OriginalLayer` raises `ImmutableOriginalError` on any attribute assignment or deletion.
  - Its sample array is a read-only numpy view of an immutable `bytes` object. numpy raises on writes and refuses to re-enable writing.
  - The store has no update path. `update_original` and `delete_original` exist only to raise.
  - Files are created exclusively (atomic hard link) and made read-only.
  - Every load re-encodes the rows and rechecks the hash; any mismatch raises `IntegrityError`. `verify()` rechecks everything.
  - A modified copy of the samples is simply a *different* original, with a different address.

### Note manifest

- One per logged session. `note_id = "note-" + sha256(device_id:session_id:original_sha256)[:16]`, so re-importing a log is idempotent.
- Contents:
  - the header, with u64 ids stored as decimal strings;
  - all events, with unwrapped 64-bit `t_us`;
  - annotations;
  - the source file SHA-256;
  - the full parse report (record counts, CRC failures, bytes skipped, wrap handling, stroke plausibility checks);
  - labels (for example `synthetic`, set automatically from a `SYNTHETIC...` annotation).
- It is write-once and protected by a digest.

### Derived layers

All derived layers are append-only and write-once. Each carries the ICD fields:

- `layer_id`, which is `<kind>-` plus 16 hex digits of SHA-256 over {kind, note_ids, created_by, inputs, params, payload}. Recomputing the same thing therefore gives the same id, and it is stored once.
- `kind`.
- `created_by`: `<algorithm>@<version>`, or `user`.
- `inputs`: a list of `{type: original, sha256, stroke_ranges}`, `{type: layer, layer_id, span_ids}`, `{type: source_file, sha256, record_type, fields}` or `{type: external_file, sha256, role}`.
- `created_utc`.
- `params`, `payload` and a `digest`.

On write the store checks:

- every stroke range against the original, so links cannot point at strokes that do not exist;
- that every text span links to at least one stroke;
- that `user_edit` keeps the edited span's stroke links and is `created_by: user`;
- that every `ai_summary` sentence has at least one citation pointing to `recognition` or `user_edit` spans;
- that assistant output can never become an input to note-content layers.

| kind | payload (schema `$defs/payload_<kind>`) | producer |
|---|---|---|
| `segmentation` | stroke table (index range, times, bbox, length, flags `short`, `single_sample`, `dropout`, `non_contiguous`, `no_pen_*_event`) + line/word spans as stroke ranges | `capture.add_segmentation_layer` |
| `hand_path_estimate` | per stroke: housing path p_H at the stroke-sample times, with the origin alignment used | `capture.add_hand_path_layer` (needs 0x01 frames) |
| `recognition` | line and word spans with `text`, `stroke_ranges`, `bbox_um`, `confidence` | `recognize.run_recognizer` |
| `user_edit` | `target_layer`, edits {span_id, text, previous_text, stroke_ranges} | `NoteStore.add_user_edit` |
| `ai_summary` | question, cited sentences, sources shown to the model, model id/version/locality, validation settings, disclaimer | `grounded.GroundedAssistant` |

**Effective text.** The effective text is the most recent `recognition` layer plus the `user_edit` layers that target it. Edits that target an older recognition layer are reported as stale; they are not silently re-applied.

**Schema.** The schema is `data/schema/note_store.schema.json` (JSON Schema 2020-12).

- The root is an export bundle (`NoteStore.export_bundle`).
- Each stored object is validated against its own `$defs` entry.
- For originals, jsonschema checks the envelope and up to 200 rows. Every row's integer range is also checked in vectorised form when the layer is loaded, because per-row jsonschema checking of an hour of samples (720 k rows) would take minutes.

**Erasure.** `purge_note(note_id, confirm=note_id)` deletes a note, every derived layer that used it (including cross-note answers) and its original if no other note shares it. It exists for the user's right to erase their data. It is explicit, confirmed deletion, not modification.

## ICD interpretations and ambiguities

The firmware sources were read (not modified) to check each interpretation against what the firmware actually does. The reader parses the firmware team's `firmware/tests/vectors/golden_log_v1.bin` in strict mode with zero issues; its decoded values match their C generator (`test_golden_vector.py`).

| # | ICD text | Issue | Implemented interpretation |
|---|---|---|---|
| A1 | 0x02 `theta, phi` u8, "0.5° (θ 0–90°, φ 0–360° as φ/2)" | φ does not fit a u8 at 0.5° | θ_raw = round(θ/0.5°), clipped 0–180; φ_raw = round(φ/2°) mod 180 (2° LSB). The firmware made the same choice (its D5). Values of θ_raw above 180 are flagged. |
| A2 | "crc16" | byte order not stated | Little-endian, like every field (firmware agrees). |
| A3 | "crc16 (CCITT-FALSE over type..payload)" | coverage | Covers the type, length and payload bytes (firmware agrees). |
| A4 | "wrap counter in events" (0x0009) | `arg` meaning | The firmware logs `arg = 0` as a marker on the first tick after the wrap. The reader accepts `arg = 0` as a marker and `arg >= 1` as a wrap count, plus backward-jump detection, without double counting. **Proposal:** use the count, because it survives lost events and silent gaps. |
| A5 | 0x02 `t_ms` u32 "ms since session start" | the firmware writes `t_us / 1000` from the **32-bit** µs counter | `t_ms` restarts every 4 294 967.296 ms (71.6 min), not after 49.7 days. The reader detects this from the wrap events (or the value pattern), corrects it to within 1 ms and reports `t_ms_follows_t_us_wrap`. **Proposal:** derive `t_ms` from a 64-bit time. |
| A6 | 0x04 calibration snapshot, 0x05 annotation | payloads undefined | The firmware-proposed layouts are adopted: `cal_type u8, cal_version u16, record` and `t_us u32, UTF-8`. Raw bytes are always kept. |
| A7 | 0x01 `p_Hx, p_Hy` "page frame" vs 0x02 `x, y` "page origin = first contact" | origins | The firmware logs p_H in its fusion frame, with no page-origin offset. The hand-path layer estimates the offset by least squares from the firmware relation ink = p_H + J·q − origin over all stroke samples. The layer records the fitted offset, a 2×2 J estimate and the residual. |
| A8 | 0x02 at 200 Hz | derivation not specified | The firmware takes a point sample on every 10th 2 kHz tick. The analysis assumes point sampling; a boxcar decimator is reported as a sensitivity case. |
| A9 | stroke samples, `stroke_id` "monotonically increasing" | hover samples? start value? contiguity? | Samples are logged only in contact (firmware agrees). The id increments at pen-down, and the firmware's first stroke is 1. Ids can be skipped when a contact has no sample on the 5 ms grid; this occurs in the simulator session. The app never assumes contiguity. |
| A10 | "first contact of the page session" | no page id and no page-change event; origin instant | One session is treated as one page. The firmware sets the origin at the first emitted sample, so that sample is exactly (0, 0). |
| A11 | event `arg` of pen down/up and mode change; mode numbering | undefined | The firmware writes 0 for pen events and `new | old << 8` for mode change, with section 6 order numbering (OFF = 0 ... SAFE_PASSIVE = 7). The synthetic logs follow the firmware. **Proposal:** use pen-event `arg = stroke_id`. |
| A12 | "list of stroke samples exactly as logged, content-addressed" | what is hashed | The SHA-256 covers only the concatenated 0x02 payloads. The header, framing and other records go in the manifest. |
| A13 | note store "(app side, JSON)" | store technology | A directory of JSON documents. SQLite is used only for the rebuildable search index. |
| A14 | 0x02 `force` "mN (axial)" | the simulator has the normal force N only | The synthetic sessions use N·sin θ (μ = 0) as an axial proxy, documented in the sample metadata. |
| A15 | research frame 2 kHz | the simulator traces are 1 kHz | The synthetic simulator session writes 0x01 frames at 1 kHz. The reader does not assume a rate. |
| A16 | one header per stream | concatenated sessions (for example a BLE reconnect) | Not defined. One header per file is required. |

## Capture fidelity of the 200 Hz / 1 µm stroke format

**Command.** `python -m penapp fidelity` writes `results/app/capture_fidelity.json`. The file lists the SHA-256 of every input trace, because other jobs regenerate those files.

**Reference.**

- The reference is the deposited-ink position (`tip`) of the coupled-simulator traces, at 1 kHz in float32. `sim/run_nominal.py` decimated them from 2 kHz.
- Scenario: seed 200, 9 Hz 0.3 mm tremor, altitude 50°, 1 N.
- Strokes are the contact runs. The page origin is the first-contact ink position.
- Traces with identical content are counted once: `neutral` is byte-identical to `kf_bal` in the current results.
- The analysis therefore covers 6 traces: 18 strokes of at least 50 ms and 12 short contacts, each evaluated at all five 1 ms sampling phases of the 5 ms grid.

**Metrics per stroke:**

- **Time-aligned deviation.** Captured samples are linearly interpolated at the reference times. Reference points before the first or after the last captured sample are compared with that endpoint (end truncation). This coupling is an upper bound on the Fréchet distance.
- **Exact discrete Fréchet distance** (Eiter–Mannila), computed after densifying both polylines to edges of 2 µm or less, so the continuous Fréchet distance lies within 2 µm below the reported value. It is computed by a banded dynamic programme around the time correspondence. The result is *certified*: if any coupling leaving the band would be worse than the banded optimum, that optimum is global; otherwise the band is widened. It is cross-checked against a plain O(nm) implementation in the tests.
- **Consistency check.** Every interior maximum is compared with the linear-interpolation bound a_max·T²/8 + 0.71 µm. It holds for 90/90 stroke evaluations.

| Variant (strokes of at least 50 ms; worst case over traces and phases) | max dev. µm | RMS µm | interior max µm | interior RMS µm | end truncation µm | Fréchet median / p95 / max µm |
|---|---|---|---|---|---|---|
| **ICD 0x02 as specified** (point sample every 5 ms, 1 µm) | **120.6** | **3.6** | 75.6 | 3.0 | 120.6 | 45.6 / 112.1 / 120.6 |
| sampling only (no rounding) | 120.7 | 3.6 | 76.0 | 3.0 | 120.7 | 46.0 / 112.5 / 120.7 |
| quantisation only (1 kHz rounded to 1 µm) | 0.70 | 0.409 (theory 0.408) | 0.70 | 0.409 | 0 | 1.08 / 1.12 / 1.13 (2 µm densification bound) |
| centred 5 ms boxcar instead of point sampling | 121.1 | 3.9 | 55.5 | 3.4 | 121.1 | 44.9 / 103.4 / 121.1 |
| **+ extra samples at pen-down/up instants** (proposal) | **81.5** | **3.0** | 81.5 | 3.0 | 0 | **9.4 / 33.0 / 76.0** |

**Reading (simulation-derived; not a measurement):**

1. The RMS error of the format is a few µm. The 1 µm LSB contributes at most 0.7 µm; the error is set by temporal sampling.
2. **End truncation dominates the maximum.** The first or last sample can land up to 4 ms inside the contact while the pen moves, giving up to 121 µm. It also inflates the Fréchet distance (median 46 µm).
3. **Short contacts are lost.** Of the 60 short-contact evaluations (simulated bounces under 50 ms), 22 produced no sample at all and 38 produced a single sample.
4. Emitting one extra sample at pen-down and one at pen-up (off-grid timestamps) removes truncation and loss. The Fréchet median falls to 9.4 µm and the p95 to 33 µm.
5. The largest remaining interior deviations sit within 50 ms of touchdown in 52 of 90 evaluations. These are simulated contact transients with accelerations that a 200 Hz point sampler cannot follow. The simulator's contact model is unidentified, so their size on paper is unknown.
6. A discrete Fréchet on the raw vertices (1 kHz against 200 Hz) gives a median of 111 µm. That figure measures vertex spacing, not capture error, which is why the densified value is reported.
7. For scale, DeltaPen optical-flow tracking reports 0.068 mm mean absolute error per 10 ms window (ledger OPT-02). Sensing, not the format, is expected to dominate capture error.
8. None of this says anything about sensor accuracy; that needs the bench protocol.

**Recommendations for ICD v1.1:**

- endpoint samples at pen-down/up;
- a specified decimation (point sample and timestamp convention);
- a 64-bit-derived `t_ms`;
- a wrap-count `arg`;
- a defined p_H origin (or a logged page origin);
- a page identifier.

## Segmentation and hand path

- **Strokes** come from the logged `stroke_id` runs. They are cross-checked against pen-down/up events and flagged, never corrected.
- **Lines** start when a stroke's vertical centre leaves the running median of the current line by more than 1.1 x-heights.
- **Words** start at horizontal gaps above 0.6 x-heights. The x-height is estimated as the median height of non-trivial strokes. This is a left-to-right heuristic.
- **Results on the synthetic notes:**
  - 16/16 and 14/14 words recovered with exactly the ground-truth stroke ids;
  - 3/3 lines in both notes.
- **Resampling.** `resample_time`, `resample_arclength` and `densify` serve recogniser adapters and the metrics; they never touch the original.
- **Hand path in the simulator session:**
  - ink minus hand-path estimate: RMS 225 µm, max 462 µm. This is the stage correction of the simulated assertive Kalman run.
  - origin fit residual: 23 µm RMS. The residual is non-zero because the simulated ink also carries passive compliance that q does not measure. The fitted constant offset absorbs its mean, so the estimate means "ink path without active correction".

## Rendering

`render_svg` and `render_note` produce deterministic SVG:

- page µm are mapped to mm with y flipped, so the page frame reads y up;
- each stroke is a polyline, and a single-sample stroke is drawn as a dot;
- a force-to-width option quantises widths into 8 levels over 0–2 N;
- overlays: hand-path estimate, segmentation boxes, or recognised or effective text (user edits in orange);
- strokes cited by an answer can be highlighted, with a caption;
- a legend gives the original's SHA-256 and the overlay layer ids;
- labelled notes carry a red "SYNTHETIC DATA" banner;
- `data-stroke-id`, `data-span-id` and `data-layer-id` attributes keep the SVG machine-traceable.

## Recognition

### Interface and implementations

`Recognizer.recognize(original, segmentation) -> RecognitionResult`. The result holds line and word spans with text, stroke ranges and boxes. `run_recognizer` stores it as a `recognition` layer, with `created_by = <id>@<version>` and the inputs used.

- `NullRecognizer` records that nothing was recognised.
- `GroundTruthRecognizer` passes through the generator's transcript of a **synthetic** session. It is labelled `GROUND-TRUTH PASSTHROUGH`; its CER is 0 by construction. Strokes lost to log corruption are dropped from the links and reported.
- `ErrorInjectingRecognizer(base, cer, seed)` produces seeded character substitutions, deletions and insertions. The achieved CER is measured and stored, and it runs below the target because spaces are never corrupted. It implements the CER-band stress test recommended in `docs/research/notes/OPT_tracking_capture_recognition.md` section 2.4.
- `MLKitDigitalInkAdapter` is a **specification**. It is not runnable here, because ML Kit Digital Ink is an Android/iOS SDK. The stroke mapping `to_ink` is implemented and tested:
  - mm, with y negated for screen coordinates;
  - epoch-ms timestamps;
  - one `Ink` per segmentation line.

  ML Kit returns text without stroke alignment, so the adapter links whole line spans. It forms word spans only when the recognised and segmented word counts agree. Recognising raises until the user has consented to ML Kit's usage-metric reporting to Google.

### Evaluation protocol (to run on real ink; nothing here is a recognition result)

**Metrics.**

- CER = Levenshtein character edits / reference characters. WER is the same on whitespace tokens.
- Both are micro-averaged over lines (`recognize.evaluate_lines`), against a double-keyed human transcript (normalised case and whitespace, punctuation kept).
- Report per writer and pooled, with 95 % bootstrap CIs resampled **by writer**.
- Report separately for:
  1. relative-only capture versus pattern-anchored (Anoto/Ncode) capture;
  2. each tremor severity band (EXP-H01 census);
  3. the ML Kit, MyScript and research recogniser variants.

**Splits.** Splits must be **writer-disjoint**: no writer appears in more than one of train, validation and test, and sessions of one writer never straddle splits. Recogniser settings and language models are frozen before the test split is opened. Report the writer count and characters per split.

**Datasets and licences** (ledger OPT-15, OPT-28 to OPT-31):

- IAM-OnDB, DeepWriting (CC BY-NC-SA 4.0 plus IAM-OnDB registration), MathWriting (CC BY-NC-SA 4.0) and BRUSH (non-commercial research only) may be used **only for non-commercial benchmarking**.
- The licences of OnHW, CASIA and CROHME are unverified; do not use them until they are verified.
- Shipped models must come from a vendor licence or from self-collected data whose consent covers training.
- Record each dataset's licence and version in `created_by`/`params`.

**Error chain.** Recognition CER, then the assistant's faithfulness to the recognised text, then correctness against the human transcript. A summary can be faithful to misrecognised text and still be wrong.

**Current synthetic stress test** (`demo_report.json`, `cer_stress_test`; 2 notes, 5 seeds per band):

| mean achieved CER | word-search recall (mean / min) | answerable questions answered, correct citation (of 2) |
|---|---|---|
| 0 | 1.00 / 1.00 | 2.0 |
| 0.028 | 0.83 / 0.67 | 1.8 |
| 0.061 | 0.69 / 0.46 | 1.6 |
| 0.143 | 0.43 / 0.29 | 1.6 |
| 0.232 | 0.23 / 0.04 | 0.8 |

Every answer that was given cited the correct line. As errors grow, the assistant's recall falls; its precision does not.

## Search

- **Index.** SQLite FTS5 with the `porter unicode61 remove_diacritics 2` tokenizer, one row per recognised line of the effective text.
- **Query safety.** User queries are converted to quoted terms and phrases, so FTS5 operators and SQL fragments are inert (tested).
- **Hits.** Each hit returns the line, a BM25 score, the layer ids (recognition plus user edits) and, for each matched word, its stroke-id ranges and page bounding box.
- The index is a derived cache: `rebuild()` recreates it from the store, and `is_stale()` detects new layers. Assistant output is never indexed.

## Source-grounded assistant

**Pipeline:**

1. Scope screen.
2. Retrieval: FTS5 OR-query of the question's content words. A passage is kept only if it covers at least 50 % of those words.
3. `LLMClient.complete(LLMRequest)`. The request carries only the question and the numbered excerpt *texts*: no ink, no timing, no identifiers.
4. Validation.
5. Storage as an `ai_summary` layer.

**Enforced properties (all tested in `tests/test_grounded.py`):**

- **Refusal without support.** If no note supports the question, the assistant refuses with `no_supporting_notes` and the model is not called.
- **Every sentence is cited.** Every sentence must end with `[S#]` markers naming sources that were actually provided.
- **Support checks.** The sentence's content words must be at least 75 % present in the cited sources, and every number must appear there exactly.
- **All-or-nothing.** Any violation rejects the *whole* answer and nothing is stored. Rejected cases include:
  - a sentence without a citation;
  - an unknown source;
  - an unsupported claim;
  - a wrong number;
  - two sentences sharing one citation;
  - a bare citation;
  - empty output.
- **Traceable citations.** Each citation resolves to note id, layer ids, span id, stroke-id ranges and page box.
- **Provenance and storage.** Answers are stored only as `ai_summary` layers, with provenance: model id and version, locality, determinism, retrieval settings, the sources shown and any consent record. Originals are byte-identical before and after (tested).
- **Consent before cloud use.** A non-local model raises `ConsentRequiredError` unless an explicit `CloudConsent` for that model id exists. The default is `ExtractiveLLM`: deterministic, local, quoting the best-matching note lines verbatim. `RemoteLLMClientSpec` shows the plug-in point and makes no call.
- **No clinical inference.** Questions asking for clinical inferences about tremor, handwriting or health are refused (`out_of_scope_clinical`). The screen is a conservative keyword filter, not a classifier; false refusals are preferred.

**Limitations.** The lexical support test is necessary but not sufficient for faithfulness.

**Evaluation plan** (per the OPT notes, section 2.4):

- AIS two-stage human judgement per sentence, with Krippendorff's α;
- ALCE-style citation recall and precision from an NLI judge, revalidated on our own noisy notes;
- FActScore atomic-fact precision against both the recognised text and the human transcript;
- all of the above reported as a function of CER band.

## Privacy and safety

- **Local-first.**
  - Logs, the note store and the index stay on the user's device.
  - Recognition and the default assistant run locally.
  - Nothing in this package opens a network connection.
- **Explicit consent before any cloud processing:**
  - A non-local `LLMClient` needs a `CloudConsent(granted, model_id, granted_utc, scope)`. The consent is stored with each answer it enabled.
  - The ML Kit adapter needs consent to Google's usage-metric reporting.
  - Consent is per model and can be withheld without losing any local function.
- **Data minimisation.** Models receive recognised text excerpts only. Stroke kinematics (timing, force, tremor content) never leave the note store for assistant purposes, because they are health-relevant data.
- **Not a medical device.**
  - The assistant makes no clinical inferences from handwriting, strokes, tremor or force. It refuses such questions.
  - Every stored answer carries that disclaimer.
  - Hand-path and fidelity outputs are engineering diagnostics, not assessments of a person.
- **Integrity and control.**
  - Originals are immutable and verifiable.
  - Every derived item names its inputs and producer.
  - The user can correct text (`user_edit`) without touching the ink.
  - The user can erase a note completely (`purge_note`, confirmed).
- **Synthetic labelling.** Synthetic sessions carry a `SYNTHETIC` annotation that becomes a `synthetic` label and a red banner on renders. Every results file carries an evidence-status field.

## Implemented vs design-only

| Item | Status |
|---|---|
| ICD section 4 reader/writer, CRC, resync, wrap handling, firmware conventions (A4–A7) | implemented, tested, cross-checked on the firmware golden vector |
| Note store, schema, provenance, immutability, integrity verification, export, erasure | implemented, tested |
| Segmentation (strokes, lines, words), resampling, hand-path layer | implemented, tested on synthetic data |
| Capture-fidelity analysis | implemented; results are simulation-derived |
| SVG rendering | implemented, tested |
| Recogniser interface; null / ground-truth / error-injection recognisers; CER/WER | implemented, tested |
| ML Kit Digital Ink adapter | **design-only** (data mapping implemented and tested) |
| MyScript iink (math/diagrams) | **design-only**, licence negotiation first (OPT-22) |
| FTS5 search with stroke/box links | implemented, tested |
| Grounded assistant, extractive local model, validator, consent gate, scope screen | implemented, tested |
| Cloud LLM client | **design-only** (`RemoteLLMClientSpec`; no network code) |
| NLI/AIS faithfulness evaluation, human recognition evaluation | **protocol only** (needs real ink and raters) |
| Mobile UI, BLE transport, encryption at rest, sync/backup | **not implemented** |

## Demo outputs (synthetic)

- `data/samples/`:
  - `demo_text_errands.*` and `demo_text_project.*` (log, ground-truth transcript, metadata);
  - `demo_sim_kf_asr.*` (0x02 + 0x01 + events from the Kalman-assertive trace);
  - `icd_v1_example.penlog` + `.json`: every record type, extremes, both wrap forms and three corruption cases with the reader's expected behaviour, for cross-team parser checks.
- `results/app/`:
  - `demo_report.json`;
  - `capture_fidelity.json`;
  - SVGs: force width, recognised-text overlay, simulator hand-path overlay, answer highlight, user-edit overlay;
  - `demo_store/`: the note store itself, with a fixed synthetic clock so that it is reproducible.

## Tests

`python3 -m pytest app/tests -q` runs 137 tests, all passing, including the cross-check against the firmware's golden log and its JSON decode (ICD v1.3: CAL_USER v2 snapshot, pen-up boundary sample, timestamp-wrap event, model hash 0xa57d81f6). The suite takes about 6 s. Coverage includes:

- byte layouts checked by hand against an independent bitwise CRC;
- resync fuzzing: no false record is ever accepted;
- all wrap cases, including the firmware `t_ms` restart;
- immutability and tamper detection;
- link and provenance validation;
- segmentation against ground truth;
- Fréchet implementations agreeing, with the band certificate;
- analytic fidelity cases: straight line, circle chord, uniform-rounding RMS;
- SVG geometry;
- recogniser contracts;
- search links and hostile queries;
- all assistant properties;
- the CLI and `python -m penapp`.

## Open issues

1. **ICD v1.1 decisions needed.** A4, A5 and A7 are firmware/ICD mismatches; A1, A6, A8–A11 and A16 are undefined in the ICD; the endpoint-sample proposal is in "Capture fidelity".
2. **Firmware `t_ms` restart.** The firmware's `t_ms = t_us / 1000` restarts at 71.6 min (A5). The reader corrects it to within 1 ms, but the firmware should be fixed.
3. **Hand-path J model.** The estimate assumes a constant J over the session, while tilt changes J (COR-04). A time-varying fit, or logging J / γ, would tighten it.
4. **No real recogniser runs here.** Recognition quality, and therefore search and assistant quality on real ink, is unknown until the protocol above is executed.
5. **Segmentation heuristics.** They assume left-to-right lines and are tuned on synthetic glyphs. They need evaluation on real ink, including delayed strokes, other scripts and diagrams.
6. **Stale user edits.** Edits do not follow a re-run recogniser. A span-alignment step is needed to carry corrections across.
7. **Assistant support check.** The check is lexical and the extractive model cannot paraphrase or combine. A local NLI verifier and a small on-device generator are the next step, with the evaluation plan above.
8. **Clinical-scope screen.** It is keyword-based and should be replaced by a validated classifier with a documented false-refusal rate.
9. **Reader performance.** The pure-Python reader handles 200 Hz logs comfortably, but a 2 kHz research log of 1 h (about 400 MB) needs a vectorised fast path.
10. **Store limitations.** There is no encryption at rest, no multi-device sync and no concurrent-writer locking.
11. **Moving simulator inputs.** The simulator traces are regenerated by other jobs. The fidelity JSON pins the input SHA-256 values, so rerun `python -m penapp fidelity` after simulator changes. In the current traces, `traces_kf_bal.npz` equals `traces_neutral.npz` (seed 200 at 9 Hz; `metrics.json` also shows ratio 1.000), so the balanced estimator did not engage in that run.

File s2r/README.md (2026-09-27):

# s2r: sim-to-real methodology (built and demonstrated in simulation)

**Evidence status: SIMULATION and CALCULATION only.** The "bench" here is virtual: M1 (`sim/pensim`) or small standalone models with hidden true parameters, seen through measurement models of the instruments named in `validation/bench_protocols.md`. Twin experiments show that the identification and calibration method works on data whose structure we control. They do not show that M1 is right about the real pen; only the bench can. Nothing here is a measurement.

Report: [`docs/sim_to_real.md`](../docs/sim_to_real.md). Procedure for the bench: [`validation/sim_to_real.md`](../validation/sim_to_real.md).

## Modules

| Module | Role |
|---|---|
| `instruments.py` | Measurement models (noise, bandwidth, mounted resonance, sampling, latency, jitter, quantisation, session gain/offset/non-linearity, cross-clock sync). Every number is labelled PROTOCOL, CONFIG, DESIGN or ASSUMPTION (`provenance_table()`). |
| `truth.py` | Hidden plants: draws inside the declared ranges of `config/parameters.yaml` or partly outside them; groups by the experiment that measures them; SHA-256 commitment. |
| `twin.py` | Plant/controller separation around M1 (the firmware keeps its nominal constants while the plant changes), and the C2 outcome evaluation (oracle and Kalman ratios, distortion, neutral ink error, static hold power, device distortion). |
| `fastharness.py` | Drop-in for `sim.pensim.harness.eval_case/run_cases` with a memory-mapped scenario cache and a persistent 2-process pool (identical outputs, tested). |
| `exp_b03.py` | EXP-B03 coupon: R20 (4-wire), voltage-step L (scope), blocked force K_f (F/T), back-EMF K_f (LDV), thermal step R_th, C_th. |
| `exp_b05.py` | EXP-B05 on M1 itself as a test build (clamped pen, Hall frozen, current injection): IV-FRF (m_eq, k_tip, ζ), pen-log FRF (loop and Hall delay), static tip stiffness, axial path. |
| `exp_b01b02.py` | EXP-B01/B02 tribometer with M1's contact and LuGre equations (numba): indentation, sliding, velocity steps, sweeps, reciprocation; Stribeck, pre-sliding and paper-stiffness identification; Maxwell-slip friction-memory truth for C3. |
| `pipeline.py` | The calibration pipeline in protocol order (B03 → B05 → B01/B02) and scoring against the revealed truth. |
| `ident.py` | Least squares with Laplace covariance, bootstrap, H1 and instrumental-variable FRF, second-order-plus-delay fit, Ljung-Box, input cross-correlation, band misfit, drift test, GUM combination. |
| `stage_model.py`, `modelform.py` | C3 structural truths (flexure mode, extra delay and jitter, pivot Coulomb friction, backlash) and the residual diagnostics. |
| `piezo.py` | Pencil piezo stage: Bouc-Wen truth, Prandtl-Ishlinskii identification and analytic inverse, feedforward and feedback tracking. |
| `io.py` | Bench-file layout `s2r-bench-1` (manifest + per-record arrays + JSON sidecars), read by the pipeline. |

## Run

```bash
python3 -m pytest s2r/tests -q                 # 22 tests, about 25 s with a warm numba cache (first run compiles into s2r/build/)
bash s2r/run_all.sh                            # full chain, about 30 min on 2 processes; logs in results/s2r/logs/
```

| Script | Output (`results/s2r/`) | Runtime (2 processes, shared machine) |
|---|---|---|
| `python3 -m s2r.run_c1_identify` | `c1_identification.json`, `fig_c1_recovery.png` | about 2-3 min |
| `python3 -m s2r.run_c1_benchtime --only B05`, `--only B01B02`, `--only B03` (merged into one file; `--replot` redraws the figure) | `c1_bench_time.json`, `fig_c1_bench_time.png` | about 10 min in all: B05 1 min, B01/B02 8 min, B03 1 min. The first run (one call) took 36 min: BLAS thread pools oversubscribed the shared cores. `s2r/__init__.py` now pins one thread per process |
| `python3 -m s2r.run_c2_twin --part 1`, `--part 2`, `--merge` | `c2_twin.json`, `fig_c2_gap.png` | about 4 min per part |
| `python3 -m s2r.run_c2_sensitivity` | `c2_sensitivity.json`, `fig_c2_sensitivity.png` | about 3 min |
| `python3 -m s2r.run_c3_modelform` | `c3_modelform.json`, `fig_c3_model_form.png` | about 2-3 min |
| `python3 -m s2r.run_c3_piezo` | `c3_piezo.json`, `fig_c3_piezo.png` | under 1 min |
| `python3 -m s2r.run_c4_domain` | `c4_domain.json`, `fig_c4_domain.png` | about 4-5 min |
| `python3 -m s2r.run_c5_example` | `c5_example.json`, `virtual_bench_example/` (2.9 MB) | under 1 min |

Every script accepts `--quick` for a smoke run. Every JSON carries `stabpen.provenance.metadata()` (git revision, parameter version and digest, seeds, command).

## Rules this package keeps

- It never writes under `sim/`, `stabpen/`, `config/`, `firmware/`, `ml/` or `app/`. The numba cache goes to `s2r/build/numba_cache` (set in `s2r/__init__.py`); scenario caches to `s2r/build/scn_cache` (both git-ignored via `build/`).
- At most 2 worker processes, one BLAS/OpenMP/numba thread each (set in `s2r/__init__.py`).
- Identification code receives datasets only; hidden truths and session errors live under `_hidden` keys that `io.save` never writes.

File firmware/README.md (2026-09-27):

# Firmware baseline: stabilisation pen, research prototype Rev A

**Status: proposed design.**
- Host-tested: x86-64 with ASan and UBSan, against golden vectors from the simulator.
- Compiled and linked for the nRF5340 application core. It has **not run on hardware**.
- Executed as unit tests on QEMU `mps2-an505`, a Cortex-M33 emulator that is not cycle-accurate.

Nothing in this directory is a hardware measurement. Every number below carries its evidence label: *host test*, *QEMU execution*, *build artefact* or *proposed*. Register-level code that could not be checked against the nRF5340 or TMAG5170 documentation is marked `VERIFY`.

Contract documents:
- `docs/icd.md` v1.3 (the ML guard implements the §5 guard rules 1–4 of v1.1, rule 5 and the output expiry of contract v1.2);
- `config/parameters.yaml` v0.4.4;
- `results/sim/estimator_selection.json`;
- `results/electronics/drive_sense.json` v0.4.4 and `electronics/calcs/drive_sense.py` (sense chain, PWM, hold current, headroom);
- `electronics/gen/design_revA.py` (pin plan and fault logic);
- `results/thermal/thermal.json` (two-node thermal model).

## 1. Directory map

| Path | Content |
|---|---|
| `include/`, `core/` | Portable control core, C11. No dynamic allocation; float32 only in control code. Builds with `-Wall -Wextra -Werror -Wdouble-promotion -Wconversion -Wsign-conversion -Wshadow -Wstrict-prototypes -Wmissing-prototypes -Wundef -Wcast-align -Wformat=2 -Wvla`. |
| `include/params_gen.h`, `.json` | 212 constants generated from the YAML, the simulator, the estimator selection and drive_sense by `tools/gen_params.py`. Do not edit. |
| `include/hal.h` | Hardware interface. The control core never touches registers. |
| `port/host/` | Host HAL, including a behavioural model of the Rev A over-current latch and the ACT_EN AND gate. |
| `port/nrf5340/` | Application-core port: start-up, linker script, register definitions, PWM→DPPI→SAADC scheduler, GPIO/WDT/time-base HAL (including the coil-former NTC on AIN3), sensor front ends and log ring. **Compile-tested only; VERIFY throughout.** |
| `port/qemu_an505/` | Start-up and linker script for running the unit tests under semihosting on QEMU `mps2-an505`, plus the instruction-count bench (`bench_an505.c`). |
| `tests/` | Test runner and 60 cases. Also contains `plant.c`, a switched-bridge coil and stage plant at PWM-clock resolution, and `vec.c`, the golden-vector reader. |
| `tests/vectors/` | Golden vectors (`PENVEC01` float32 files with JSON sidecars). Also `golden_log_v1.bin` and `golden_log_v1.json`. |
| `tools/` | Scripts: `gen_params.py`, `gen_vectors.py`, `check_inputs.py` (freshness), `pen_log.py` (independent ICD §4 decoder and encoder), `size_report.py`, `run_qemu.py`. |
| `../results/firmware/` | `test_report.txt` (host), `size_report.txt` (ARM), `qemu_report.txt` (QEMU). |

## 2. Architecture

```
 port (nRF5340)                 core/app.c (application layer)            core modules
 ─────────────────              ───────────────────────────────           ─────────────────────────────
 SAADC END IRQ (40 kHz) ──────► pen_app_current_isr()  ─────────────────► current_loop.c (PI, bridge map)
 EGU0 IRQ (2 kHz)        ─┐                                               hall.c, fusion.c
 sensors_read() ──────────┴───► pen_app_stage_tick()  ──┬───────────────► safety.c, thermal.c (two-node)
                                                        ├───────────────► state_machine.c
                                                        ├───────────────► control.c ─► estimator_kf.c / estimator_bpf.c /
                                                        │                               guided.c, jacobian.c, limiter.c, servo.c
                                                        ├───────────────► ml_guard.c (window, guard)
 board_log_sink() ◄── ring ◄────────────────────────────┴───────────────► log_format.c, crc16.c (capture layer)
 main loop: WFI, drain the ring to USB CDC (transport not implemented)    calib.c (records, f0 calibration)
```

The control core (`core/control.c`, `ctrl_tick()`) is a line-by-line port of the control tick of `sim/pensim/core.py` `simulate()`. It runs these steps in order:
1. estimator (Kalman oscillator, band-pass, guided, or ML via the guard);
2. authority smoothing;
3. axial compensation;
4. compliance-aware inverse Jacobian, with γ(θ) = r_n·sin²θ / (r_n·sin²θ + 1) evaluated at every update from the CAL_USER ratio r_n = K_n/k_ax (ICD §1 v1.3; the simulator's formula);
5. `lam_hat` (κ_s = 1);
6. radial tanh taper;
7. slew limit;
8. PID servo with reference, acceleration and contact feedforwards (contact feedforward gain 0, DEC-011);
9. `i_ref = −F/(n·K_f)`.

The replay tests prove the port against the numba simulator (section 7). Firmware-only additions are opt-in or documented:
- the estimator local origin (D9);
- the current-loop feedforward default (D10);
- the authority cap from the state machine and the thermal derating;
- the ML cross-fade and confidence scaling.

## 3. Timing: interrupts and the stage task (proposed design, `port/nrf5340/scheduler.c`, VERIFY)

There is one clock domain: the PWM timer (ICD §2).

| Event | Time in the 25 µs PWM period | Mechanism |
|---|---|---|
| PWM0 period | 0–25 µs | 16 MHz, up/down counter, COUNTERTOP 200, 4 channels (IN1/IN2 × x, y); the drive phase is centred on 12.5 µs |
| TIMER1 CLEAR | 0 | DPPI ch0 from PWM0 PWMPERIODEND |
| Centre scan (ISNS_X, ISNS_Y) | TIMER1 CC0 = 7.0 µs → conversions straddle 12.5 µs | DPPI ch1 → SAADC SAMPLE (TACQ 3 µs + 2 µs per channel) |
| Edge scan | CC1 = 19.5 µs → conversions straddle the period boundary (middle of the brake phase) | DPPI ch1 → SAADC SAMPLE |
| SAADC END (4 results) | ≈ 4.5 µs into the next period | DPPI ch3 → SAADC START (re-arm); END IRQ, priority 1 → **current loop** |
| New duty | written by the ISR, fetched by the PWM EasyDMA at the start of period n+2 | sample-to-update 37.5 µs; with the 10 µs anti-alias filter this is the 47.5 µs loop delay of the ICD |
| Stage tick | every 20th period (2 kHz) | TIMER2 counts PWMPERIODEND, CC0 = 20 with the clear short → DPPI ch2 → EGU0 TRIGGER0 → EGU0 IRQ, priority 3 → **stage task**. Release jitter is interrupt latency only. |
| Slow channels (VBAT, coil-former NTC) | every 20th stage tick (100 Hz) | the stage task enables 2 more channels for one scan (MAXCNT 6); the ISR stores them and restores MAXCNT 4. The ≈ 10 µs longer scan needs VERIFY with a logic analyser. |

Aggregate SAADC rate is 160 kS/s + 200 S/s, against the 200 kS/s limit (DEC-010, VERIFY).

**Current ISR** (`pen_app_current_isr`, 40 kHz):
- centre and edge samples → per-axis PI with a voltage clamp at `duty_max·V_M`, where `V_M = VBAT − R_ls·Σ|i|`, and conditional-integration anti-windup;
- duty quantised to 1/200 with error-feedback dither → DRV8212P IN/IN drive/brake mapping (D3);
- accumulators for the stage task.

**Stage task** (`pen_app_stage_tick`, 2 kHz), in order:
1. 64-bit session clock (wrap event);
2. swap of the ISR accumulators inside a short critical section;
3. Hall conversion and Hall checks;
4. fusion (optics + IMU, simulator scheme) and attitude;
5. contact and pen-up; during a Hall fault, pen-up comes from optical lift, because F_ax comes from the same sensor;
6. at 100 Hz: battery, coil-former NTC, two-node thermal estimator and derating;
7. remaining fault detections;
8. ML: realised-disturbance band-pass, window push and inference at 250 Hz, guard;
9. over-current clear sequence;
10. state machine and events;
11. `ctrl_tick`;
12. actuator policy (servo, neutral, hold open-loop, ramp 30 ms, off), then ACT_EN_REQ and DRV_SLEEP_N;
13. watchdog kick, only while the ISR is alive;
14. research frame;
15. capture layer (stroke samples).

**Instruction counts** (*QEMU execution*: `results/firmware/qemu_report.txt`, `port/qemu_an505/bench_an505.c`). Method: `-icount` makes the SysTick count executed instructions, calibrated with a loop of known length. The scenario is the closed-loop C plant in ASSIST_KF with 9 Hz tremor, authority engaged and research logging on. These are **instructions, not cycles**, measured on a non-cycle-accurate emulator. Real cycles are higher: loads, VDIV/VSQRT (14 cycles), branches, flash wait states, exception entry and exit, and the port code are not included.

| Body | Mean | Max | Budget (128 MHz) | Max / budget at CPI 1 |
|---|---|---|---|---|
| Current ISR | 422 | 446 | 3200 cycles per 25 µs | 14.0 % |
| Stage tick, steady assist | 11535 | 13112 | 64000 cycles per 500 µs (brief); 32000 = the ≤ 250 µs compute of ICD §2 | 20.5 % / 41.0 % |
| Stage tick, all ticks (incl. pen-down/up, events, 100 Hz ticks) | 9744 | 13112 | same | 20.5 % / 41.0 % |

Breakdown of one steady tick:
- 11385 instructions in total: Kalman estimator (both axes) 6866; research frame (pack + CRC + ring copy) 1627, of which the table CRC over the 52-byte payload is 425; everything else (Hall, fusion, safety, state machine, servo, Jacobian with γ(θ), limiter, ML window and guard, capture) about 2892

CRC history:
- the bitwise CRC-16 cost ≈ 3600 instructions per research frame;
- `crc16.c` is now table-driven (512 B of flash).

Mean load in assist is about 31 % of the 128 MHz core at CPI 1 (20 ISR calls + one stage tick per 500 µs). This is a lower bound. The ML inference itself is not included: no model is linked, and ICD §5 allows ≤ 1 ms per 4 ms.

The unit tests on QEMU ran 60 cases (1120 checks) on the Cortex-M33 code: FPv5-SP, newlib libm. 60 passed and 0 failed (0 failed checks), with the host tolerances. The run took 24 min of host time, because the test plant is soft double.

## 4. Module map to the ICD

| Module | ICD / requirement | Simulator reference | Tests |
|---|---|---|---|
| `current_loop.c` | §2 current loop (40 kHz, centre + edge sampling, ≤ 47.5 µs); §1 current sign | `core.py` current loop; `drive_sense.py` (PI design, D13) | `test_current.c`, `test_closed_loop.c` |
| `servo.c` | §1 signs; §2 stage loop; DEC-011 | `core.py` position servo | replays, `test_closed_loop.c` |
| `estimator_kf.c` | §1 d̂; §2 | `core._kf_step`, mode 3 | `test_kf.c` (step, sequences, replays) |
| `estimator_bpf.c`, `guided.c` | §1 d̂ | mode 2, mode 6 | `test_kf.c` |
| `jacobian.c` | §1 J and γ(θ) (v1.3) | `core.py` Ji00..Ji11; `model.py` γ formula; `stabpen/frames.py` | `test_filters.c` (frames vectors), `test_calib.c` (γ(θ), J_t1) |
| `limiter.c` | REQ-CTRL-004 (taper, slew) | `core.py` taper and slew | `test_filters.c` |
| `control.c` | §2 stage-loop order | `simulate()` control tick | replays |
| `fusion.c` | §1 p_H; §2 optics 1 kHz, IMU 3.84 kHz | `core.py` fusion | `test_sensing.c` |
| `hall.c` | §3 CAL_HALL (default map is an **uncalibrated placeholder**) | none | `test_sensing.c` |
| `thermal.c` | §6 bit 2; two-node model (YAML 0.4.4, `thermal.json`) | `core.py` one-node coil model (different, see D6) | `test_thermal.c` |
| `safety.c` | §6 fault bits 0–8; REQ-SAF-001/002 | failure cases F1–F7 | `test_safety.c`, `test_system.c` |
| `state_machine.c` | §6 modes, codes and policies; REQ-SAF-004; REQ-PWR-003 | none | `test_sm.c`, `test_system.c` |
| `ml_guard.c` | §5 v1.2 (rules 1–5, expiry); REQ-SAF-003 | none | `test_ml.c` |
| `log_format.c`, `crc16.c` | §4.1–4.4 (0x04/0x05 per v1.3) | none | `test_log.c`, `tools/pen_log.py` |
| `calib.c` | §3 container and CAL_USER v2 (v1 read with conversion); REQ-CTRL-007 (f0 calibration and f_gate rule) | none | `test_calib.c` |
| `app.c` | §2 order; §4 capture layer; §6 actuator policies | failure cases F1–F7 | `test_system.c` |
| `port/nrf5340/*` | §2 scheduler; Rev A pin plan (`design_revA.py sheet_mcu`) | none | compile and link only |

## 5. Parameters

`tools/gen_params.py` (run with `make params`) reads four sources:
- `config/parameters.yaml` through `stabpen.params`;
- `sim/pensim/model.py` `build_params()` and `Controller` (balanced and assertive profiles). Since model.py for YAML 0.4.3, `Controller.f_stage/pos_bw/cur_bw` default to `None` and resolve from the YAML inside `build_params()`. `gen_params.py` resolves them the same way and refuses to generate if the packed gains (Ts, Kp, Kp_i) were not built from those values;
- `results/sim/estimator_selection.json`;
- `results/electronics/drive_sense.json`, the output of `electronics/calcs/drive_sense.py`: sense chain, PWM, duty limit, design hold current and design coil temperature.

It writes `include/params_gen.h` (212 `#define`s, each with its source and status) and `params_gen.json`. The output is deterministic: no timestamps; the digests of every input are recorded. `tools/check_inputs.py` compares those digests with the current files. `make test` records the result in the report and **fails if the generated header or any vector is stale**. The upstream files changed several times during this work, so check this before trusting a report.

Current inputs:

| Input | Version / digest |
|---|---|
| YAML | 0.4.4 [a9d3d0016461d690] |
| estimator selection | [eace6b899bb37c3a]: balanced KF q_j 0.1, q_t 1e-8, w0 7 Hz, f_gate 7.5 Hz (the same values as the assertive profile) |
| `model.py` | [d8e582e84966892f] |
| `core.py` | [7b86d3e72d535bce] |
| `drive_sense.json` | [7fcbd6c40ee3b4af] |
| `docs/icd.md` | [7c379c5d77455a2f] (recorded; the ICD is not an input to the values) |

Notable values:

| Parameter | Value |
|---|---|
| K_f20 | 0.717 N/A |
| R20 | 6 Ω |
| L | 175 µH |
| r_bridge + r_shunt | 0.42 + 0.10 Ω |
| i_max / i_trip | 0.60 / 0.80 A |
| Kp_i / Ki_i | 2.20 V/A / 81.9 kV/(A·s) (ω_c = 2π·2 kHz, R at 20 °C; D13) |
| m_eq | 13.69 g (simulator geometry; YAML documents 13.7 g) |
| k_tip | 80 N/m |
| Kp / Kd / Ki | 1866 N/m / 7.23 N·s/m / 1.41e5 N/(m·s) |
| q_lim | 0.55 mm |
| slew | 0.08 m/s |
| horizon | 1.33 ms |
| r_n (default CAL_USER) | 0.4 = K_n/k_ax = 800/2000; γ(50°) = 0.190 |
| Thermal: coil → structure | R 145 K/W (`actuator.Rth_coil_amb`, key name historical), C 0.25 J/K |
| Thermal: structure → ambient | R 12.5 K/W, C 14.9 J/K; reference T_amb (25 °C) + 5.9 K with no coil loss |
| Thermal: time constants | 35.5 s and 190 s (coupled network); total 157.5 K/W |
| Design coil temperature | 96.6 °C (drive_sense v0.4.4, used by the hold-corner test) |
| **ff_contact** | **0.0 (DEC-011)** |

The contact feedforward path (N̂ = F_ax/sin θ through a 60 Hz, 2nd-order biquad) is kept behind that gain; the FFC replay proves it at gain 1.

## 6. Build and test

Prerequisites (versions used):
- gcc 13.3;
- arm-none-eabi-gcc 13.2.1 with newlib and newlib-nano;
- qemu-system-arm 8.2.2;
- Python 3 with numpy, scipy and numba, for the generators only. The generators import `sim/` and `stabpen/` read-only. They set `NUMBA_CACHE_DIR=firmware/build/numba_cache` and never write bytecode outside `firmware/`.

```
make params     # regenerate include/params_gen.h from the YAML (after upstream changes)
make vectors    # regenerate golden vectors, golden_log_v1.bin/.json, and verify the JSON with pen_log.py
make test       # host unit tests (ASan + UBSan) + input freshness -> results/firmware/test_report.txt
make arm        # nRF5340 image + results/firmware/size_report.txt
make qemu       # unit tests + instruction-count bench on qemu-system-arm -M mps2-an505
                # -> results/firmware/qemu_report.txt (takes tens of minutes: the plant is soft double)
make all        # test + arm + qemu      (use at most make -j2 on shared machines)
```

Useful direct invocations:
- `build/host/pen_tests tests/vectors <filter>` runs a subset of the cases.
- `tools/gen_vectors.py --only replay_kf_auth` regenerates one vector group.
- `tools/pen_log.py decode <bin> --json <out>` decodes a log to JSON.
- `tools/pen_log.py verify <bin> <json>` checks a log against its JSON.

**Size** (*build artefact*, `results/firmware/size_report.txt`, `-O2`, newlib-nano, `--gc-sections`):

| Item | Size |
|---|---|
| Flash | 32.3 kB (3.1 % of 1 MB) |
| RAM | 29.4 kB (5.6 % of 512 kB), including the 16 kB stack and the 8 kB log ring |
| Control core | 20.7 kB text |
| libm | 7.5 kB |

## 7. Verification status

Evidence labels: **H** = host test (float32 code on x86-64), **Q** = QEMU execution (Cortex-M33 code, emulator), **B** = build artefact, **P** = proposed / not verified. All host cases also run on QEMU (section 3 and `qemu_report.txt`). The numbers are the host values; the QEMU run passes the same checks, with target values printed in its log (for example KF replay i_ref 22 µA vs 15 µA on the host).

| Item (brief / requirement) | Method | Status | Result |
|---|---|---|---|
| CRC-16/CCITT-FALSE | KAT "123456789", 64 vectors vs `binascii.crc_hqx`, 448 single-bit corruptions | H, Q | 0x29B1; 0 mismatches; 448/448 detected |
| Log round-trip | header and all record types packed and unpacked; unit conversions; corruption | H, Q | pass |
| Golden log | `golden_log_v1.bin` (491 B) + `golden_log_v1.json` (CAL_USER v2 snapshot, ML model hash 0xa57d81f6); the firmware writer reproduces the file byte for byte, and the independent Python decoder re-encodes it byte-identically | H, Q (C side) | pass |
| Log fixes (1)–(5) from the project lead | 64-bit t_ms, wrap-count arg, 2° φ, pen-down/up boundary samples, page-origin p_H | H, Q | all done (section 8); documented in ICD v1.3 |
| Jacobian vs `stabpen/frames.py` | 240 poses, γ = 1 closed form and 0 ≤ γ ≤ 1 numeric construction | H, Q | max error J 2.4e-7, J⁻¹ 2.1e-7 |
| γ(θ) and J_t1 vs the simulator formula (D7) | 35°, 50°, 75° through `ctrl_tick`; replays check γ(θ_scenario) = the simulator's `gamma_acc` | H, Q | \|Δγ\| ≤ 1.5e-8, relative ΔJ_t1 ≤ 4.1e-8; γ(50°) = 0.19011 |
| CAL_USER v2 and v1 conversion | round-trip (flash record and log payload); v1 records with γ 0.05–0.8; out-of-range γ | H, Q | bit-exact round-trip; v1 γ recovered within 3e-8 after r_n = γ/((1−γ)·sin²50°); γ outside 0.0116–0.854 clamped and flagged |
| Biquads vs scipy | 60 Hz feedforward filter, BP1, BP2 (`sosfilt`) | H, Q | 3.9e-6 / 3.3e-5 / 3.9e-5 |
| Limiter and slew properties | 4000 radii, 2000 random slews | H, Q | \|q\| ≤ q_lim + 4 ulp (0.5 nm); step ≤ 40 µm per tick |
| KF step vs `core._kf_step` | 114 realistic states, covariance-normalised | H, Q | dx/σ 2.6e-5, dP 9.4e-6 |
| KF sequences (balanced, assertive) | 6000 ticks, 8→10 Hz, dropout | H, Q | d̂ 9.0e-9 m, relative ω 1.4e-6; float32 P stays SPD |
| Replay of `core.simulate()` (Kalman) | inputs reconstructed from the numba closed-loop run, 2 s | H, Q | d̂ 4.7e-9 m, f 4.8e-5 Hz, g 5.5e-6, q_r 3.4e-9 m, i_ref 15 µA; authority on in 92 % of ticks |
| Replay, Kalman 4 s / 9 Hz | same, long run | H, Q | d̂ 1.8e-8 m, q_r 5.8e-9 m, i_ref 31 µA; authority on in 96 % |
| Replay, band-pass | same | H, Q | d̂ 1.7e-7 m, q_r 1.9e-7 m, i_ref 2.1 mA. Float32 DF2T on page position; tolerance 1 µm / 5 mA; standalone BPF 1.0e-7 m |
| Replay, contact feedforward (gain 1) | same | H, Q | q_r 6.0e-9 m, i_ref 19 µA |
| Current loop | switched-bridge plant, 0→0.30 A step, 3.7 V | H, Q | rise 125 µs, overshoot 13.2 %, error −0.53 mA; simulator R·i_ref form 54.7 % (D10) |
| Voltage clamp and anti-windup | 3.0 V, 85 °C, 0.6 A request | H, Q | duty 0.970, 0.361 A; recovers to 0.20 A ±5 mA in 400 µs |
| ISNS offset calibration at pen-up | +8 / −5 mA injected | H, Q | estimated 8.06 / −5.04 mA |
| Servo + current loop closed loop ("~60 Hz") | C plant: stage, coil, bridge, ADC, delayed Hall | H, Q | 50 µm step: rise 1.5 ms, overshoot 45.8 %, 2 % settling 23 ms; −3 dB at 193 Hz, peak +4.4 dB at 80 Hz. "60 Hz" is the PID natural frequency |
| Loop margins (REQ-CTRL-002) | force injection, unloaded plant | H, Q | crossover 98 Hz, **PM 35.3° (< 40°, not met; open)**, GM 10.9 dB |
| No voltage saturation at the design hold current | 0.76 N hold (0.335 A) + 0.3 mm 8 Hz correction | H, Q | 3.7 V / 25 °C: max duty 0.66. 3.3 V, coil 96.6 °C, magnets 36.1 °C (drive_sense v0.4.4 corner): DC 0.868, peaks 0.930; no clamp, below the 0.95 headroom threshold |
| Two-node thermal estimator (D6) | constant loss and constant current (copper tempco) vs closed form; 0.30 W step response; NTC preference; derating | H, Q | steady state within 0.001 K of the closed form; time constants 35.5 s / 190.1 s from the response = network eigenvalues (R·C products 36.25 s / 186.25 s); NTC preferred when valid; derate thresholds unchanged |
| Hall frozen detection < 5 ms | unit test + system test on the plant | H, Q | 4.0 ms; no false trip in 10 s. Open-loop hold drifts 33 µm in 200 ms (release would move 600 µm) |
| Fault detections | residual, range, headroom, optical, battery | H, Q | headroom 50.5 ms; optical 300.5 ms; battery 230 ms (LPF 50 ms + debounce 200 ms) |
| Over-current latch clear | host latch model (PRE/CLR/Q, AND gate) | H, Q | clears only with ACT_EN_REQ low; FAILED after 3 retries |
| State-machine table, every fault | 18 transitions; 9 fault bits × (in contact, pen-up, timeout, self-check) | H, Q | as ICD §6 (policy per bit in section 10) |
| System fault sequences (a)–(e) | app + plant + host HAL | H, Q | pass. Watchdog kicked only while the ISR runs |
| ML guard (§5 v1.2) | injected good, bad, NaN, saturated (flag and int16 full-scale value), stale and low-confidence predictors | H, Q | rules 1–3; bad predictor → fallback 38.5 ms, Kalman fully in use 20 ms later; re-admission ≥ 1 s; expiry at t_acq + 8 ms (8.5 ms at tick granularity); rule 5: byte 255 at the defaults leaves the share unchanged, byte 0 removes it within 20 ms, c_full 0.4 with byte 51 halves it within 10 ms, c_min 0.3 rejects byte 51 |
| Calibration records and f0 | 328 corruptions; Goertzel bank; gate rule | H, Q | 328/328 rejected; peak error < 0.001 Hz |
| Fusion, attitude | vs double transcription of the simulator scheme | H, Q | 1.1e-9 m; θ, ρ, φ exact |
| Capture layer | 501.5 ms stroke across a hardware counter wrap | H, Q | 102 samples incl. pen-down and pen-up; t_ms monotonic |
| ARM build | `make arm` | B | links; sizes above |
| Target timing | QEMU icount bench | Q (instructions) | section 3; cycles **not measured** |
| Register code, DPPI chain, SAADC timing, TMAG5170 frames | none possible without hardware | P | VERIFY (section 12) |

## 8. Log format notes (ICD §4)

- Encoding is explicitly little-endian (no struct overlay). Every record is `type | len | payload | CRC-16` over type..payload. The header CRC covers the first 34 B.
- Research frame: 52 B at 2 kHz; with framing this is 56 B, 112 kB/s. p_H is an i32 in 0.1 µm. `INT32_MIN` is reserved for "undefined" (before the first pen-down). `sat_i32` clamps to `INT32_MIN + 1`.
- The project lead's fixes are **all done**, within the v1 layout (format_version stays 1). ICD v1.3 §4.2, §4.3 and §4.6 now document them as implemented:
  1. stroke `t_ms` comes from a 64-bit session time base (`penlog_clock_t`), so it no longer wraps every 71.6 min;
  2. event 0x0009 arg is the cumulative wrap count;
  3. φ is a u8 in 2° steps (0–358°) and θ is in 0.5° steps;
  4. a stroke sample is emitted at the exact pen-down tick (phase reset) and at the pen-up boundary (the last in-contact tick, unless already on the 200 Hz grid);
  5. research p_H is relative to the session page origin (the ink position at the first pen-down), the same origin as stroke x/y.
- 0x04 calibration snapshot (ICD §4.1 v1.3): `rec_type u8 | cal_version u16 | payload`, where the payload is exactly the flash container's payload (no magic, length or CRC). The application logs it together with event 0x0004 when a CAL_USER record is applied. The golden log carries a CAL_USER v2 snapshot. `pen_log.py` decodes v1 (γ) and v2 (r_n) payloads, and also the earlier container-in-record form.
- 0x05 annotation: `t_us u32 | UTF-8 text` (≤ 251 B).
- Still open for format version 2 (ICD §4.6): nib offset and uncertainty in the stroke sample, and per-page origins at event 0x000A. The codes 0x000A and 0x000B are defined and decoded, but Rev A never emits them.

## 9. ML guard (ICD §5 contract v1.2)

`ml_guard.c` implements:
1. NaN/Inf or output saturation rejects that inference. Saturation means the kernel's int16 d̂ (0.1 µm) at full scale, ±3.2767 mm: the kernel's status bit (`TCN_ST_OUTPUT_SAT`) or |d̂| ≥ 3276.65 µm in the value. int8 activation saturation is not observable and not used;
2. |d̂| is clipped to q_lim;
3. d̂ is slew-limited at 50 mm/s, over acquisition-time intervals;
4. a-posteriori check: the prediction made h = 6 ms earlier is compared with the realised disturbance (fused p_H band-passed 3–15 Hz, 2nd-order Butterworth). If the 200 ms running RMS error exceeds the running RMS of the realised disturbance, the guard falls back to the Kalman estimate for ≥ 1 s and logs event 0x0006 with a reason bit;
5. confidence (v1.2): with ĉ = confidence byte / 255, the ML share of the correction is scaled by c = min(1, ĉ/c_full), slewed so that a new value is reached within 20 ms. ĉ below c_min is a rejected inference (reason bit 0x40). c_min and c_full (0–1) come with the model card (`ml_guard_set_confidence_cal()`); the defaults are 0 and 1. An uncalibrated model reports 255 (`TCN_CONFIDENCE_UNCALIBRATED`), so the rule has no effect; a byte of 0 removes all ML authority. The share is the weight of the ML estimate in its blend with the Kalman estimate: w = cross-fade × c.

The v1 rule "|d̂ − d̂_KF| > 150 µm" is **not** present.

Other behaviour:
- **Expiry**: an output expires at t_acq_newest + 8 ms (REQ-SAF-003, REQ-ML-002).
- Every fallback and re-admission is a 20 ms cross-fade.
- More than 5 trips in 10 s set fault bit 8.

Input and hook:
- The window holds 64 × (dx, dy) µm increments, oldest first, stamped at acquisition (tick time − IMU delay). There is no f_est input.
- `pen_ml_predict(dp_um, &out)` returns d̂ in float µm (the kernel's int16 0.1 µm output), the NaN/Inf and saturation status and the confidence byte. The weak default reports that no model is linked.
- The exported model is `tcn_s_nofest` (`ml/export/tcn_model.h`: TCN_CIN 2, hash low32 0xa57d81f6, 448 B scratch). Its adapter calls `tcn_predict()` with `f_est_hz = 0.0f` (ignored), maps `TCN_ST_INPUT_NAN` / `TCN_ST_OUTPUT_SAT` to the status flags and reports confidence 255. The adapter and the link of `ml/export` into the image are ML-integration work, not in this baseline.

## 10. State machine (ICD §6)

`OFF → STANDBY → NEUTRAL_HOLD → {ASSIST_KF, ASSIST_ML, GUIDED, TRAINING_FADE}`. Any state goes to `SAFE_PASSIVE` on a fault. `SAFE_PASSIVE → STANDBY` only after pen-up and a successful self-check. Arming needs the battery to be OK and the pen not to be charging. Mode permissions come from CAL_USER (bit0 ASSIST_KF, bit1 ASSIST_ML, bit2 GUIDED, bit3 TRAINING_FADE). Disarm and off take effect at pen-up, with the 30 ms ramp.

| Fault bit | Class | In contact | After pen-up (or the 5 s timeout) |
|---|---|---|---|
| 0 over-current, 5 watchdog, 7 charging | VMOT removed by hardware | coast immediately | latch clear sequence (bit 0) and self-check |
| 1 Hall frozen / implausible | hard | hold the mean of the 8 ms of current references before the stuck run, open loop | ramp 30 ms → off (pen-up from optical lift) |
| 2 thermal, 3 battery, 4 optical, 6 headroom, 8 ML | soft | fade authority, closed-loop neutral hold | ramp 30 ms → off |

Mode codes (research frame `mode` byte, event 0x0001 arg): OFF 0, STANDBY 1, NEUTRAL_HOLD 2, ASSIST_KF 3, ASSIST_ML 4, GUIDED 5, TRAINING_FADE 6, SAFE_PASSIVE 7 (adopted by ICD v1.3 §6).

## 11. Discrepancies (simulator ↔ ICD ↔ circuit) and their status

| # | Discrepancy | Status |
|---|---|---|
| D1 | ICD §1 printed J with diag(1/J_t1, 1), the inverse of the simulator's and frames.py's diag(J_t1, 1) | **resolved upstream**: ICD v1.3 §1. The firmware always followed the simulator (verified to 2e-7) |
| D2 | ICD §1 tip force +n·K_f·i vs the simulator's −n·K_f·i | **resolved upstream**: ICD v1.3 §1 (positive current = +x_H force on the paddle; tip-equivalent −n·K_f·i) |
| D3 | `design_revA.py` note described "PWM on one input, other low" as drive/brake; under the DRV8212P IN/IN truth table that is drive/coast | **resolved upstream**: `design_revA.py` note corrected (one input high, the other with inverted duty = drive/brake, slow decay); matches the firmware mapping. The truth table itself stays VERIFY |
| D4 | 0x04/0x05 payloads and the mode codes were undefined | **resolved upstream**: ICD v1.3 §4.1 and §6. The firmware now logs 0x04 as rec_type, cal_version and the container payload only |
| D5 | φ encoding "0.5° as φ/2" did not fit a u8 | **resolved upstream**: ICD v1.2/v1.3 (2° steps) |
| D6 | Coil thermal resistance: one-node 60 → 130 K/W vs the thermal network | **resolved in firmware + upstream**: YAML 0.4.3 two-node values, `thermal.c` two-node estimator. The C_coil mismatch (thermal network 0.219 J/K vs YAML 0.25 J/K) is resolved in YAML 0.4.4: `analysis/thermal.py` takes the coil node from `actuator.Cth_coil`. The simulator keeps a one-node model against ambient, which is valid for runs much shorter than 3 min |
| D7 | Simulator γ(θ) varies with tilt; the ICD stored a fixed γ | **resolved in firmware + upstream**: ICD v1.3 CAL_USER v2 stores r_n; `control.c` evaluates γ(θ) at every Jacobian update; v1 records are converted |
| D8 | Optics "2 kHz burst" (ICD) vs 1 kHz (YAML, simulator) | **resolved upstream**: ICD v1.3 §2 (1 kHz; 2 kHz if the selected sensor allows) |
| D9 | Simulator band-pass estimator re-initialises on absolute page position: up to 10.6 mm transient at optical re-acquisition | **open (simulator)**, recorded in `docs/sim_report.md`. Firmware: local-origin option, default on (9.86 mm → 0.27 mm); replays run with it off to match |
| D10 | Simulator current loop adds R·i_ref feedforward with no sample-to-PWM delay; with the Rev A timing this overshoots 55 % | **open (simulator)**, recorded in `docs/sim_report.md`. Firmware: PI only by default (`cur_r_ff = 0`, 13 % overshoot) |
| D11 | `drive_sense.py` headroom check omitted the magnet tempco and the correction force | **resolved upstream**: drive_sense v0.4.3 (per-point coil and magnet temperatures, Br tempco, correction force). Its r_ext 0.58 Ω includes 0.06 Ω of wiring; the firmware models the shared load switch separately in V_M. The host hold test now uses the same corner |
| D12 | `ml/export/tcn_int8.h` (v1 kernel) took f_est as a third input channel | **resolved upstream**: re-exported as `tcn_s_nofest` (TCN_CIN 2, hash 0xa57d81f6); `f_est_hz` is ignored and callers pass 0.0f. The firmware hook has no f_est |
| D13 (new) | Current-loop PI: drive_sense v0.4.3 designs Kp 2.57 V/A, Ki 114.7 kV/(A·s) (2.34 kHz crossover at 50° PM, pole cancelled at the hot-coil resistance); the simulator and firmware use Kp 2.20, Ki 81.9 k (YAML `current_bw` 2 kHz, R at 20 °C) | **resolved upstream** (YAML 0.4.4): `drive_sense.py` now evaluates the implemented loop (2 kHz, zero on the cold pole: Kp 2.20 V/A, Ki 81.9 kV/(A·s), 55.8° phase margin) and reports 2.34 kHz as the 50° limit. Scheduling Ki with the thermal estimate R(T) remains a cheap option if bench tests show a slow integral tail when hot |
| D14 (new) | `core.py` applies the magnet Br tempco at the **coil** temperature; drive_sense v0.4.3 uses the magnet (structure) temperature, which is far cooler (36 °C vs 97 °C at the design corner) | **resolved upstream** (YAML 0.4.4): `core.py` applies the Br tempco at the magnet temperature, which is ambient over the simulator's short runs; `actuator.alpha_B` moved to the parameter file. The simulation chain was re-run. The host hold test follows drive_sense |
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

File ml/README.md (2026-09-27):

# ml/: causal disturbance predictor (training, comparison, edge deployment)

> **Evidence status: SIMULATION / synthetic data.**
> - The data is synthetic handwriting (sigma-lognormal, `stabpen.signals`) plus synthetic tremor, with 60 runs of the coupled simulator (`sim/pensim`) as a realism check.
> - No human recording, bench measurement or nRF5340 hardware measurement exists behind any number here.
> - Nothing here implies clinical benefit.
> - Timing numbers are calculations plus an executed-instruction count on an emulated Cortex-M33. QEMU is not cycle accurate.

## Summary

**Contract** (`docs/icd.md` §5):

- Input: 64 increments Δp_H (x, y, µm) at 250 Hz. Contract v1.0 also passed the tracked tremor frequency f_est. v1.1 dropped it because it adds nothing measurable (§c.9).
- Output: d̂ (x, y) at h = 6 ms, as int16 in 0.1 µm from the C kernel.
- Quantisation: int8.
- Budget: ≤ 35 k MAC, ≤ 32 kB, ≤ 8 kB, ≤ 1 ms at 128 MHz.

**Model.** `tcn_s` is a causal dilated TCN (kernel 2, dilations 1–32, receptive field = W = 64). It is evaluated only at the newest sample, so it reduces to 6 stride-2 "pair" layers plus a 2-layer head. With the three v1.0 inputs it has 5,942 parameters and 16,688 MAC per inference. The comparison in §c.1–c.6 uses this model.

**Exported artefact: `tcn_s_nofest`** (§c.7). It is the same network trained without f_est, so it implements contract v1.1: 2 input channels, 5,926 parameters, 16,176 MAC per inference. It is not worse than `tcn_s`: test 0.469 against 0.475, validation 0.476 against 0.486 (§c.9).

**In-distribution result (80 test writers).** At matched false correction (gain frozen on validation for FC ≤ 25 µm RMS on no-tremor writing), the residual ratio (all bands) is:

| Method | Residual ratio (all bands) |
|---|---|
| TCN (`tcn_s`) | 0.48 [0.41, 0.55] |
| TCN without f_est (`tcn_s_nofest`, exported) | 0.47 [0.40, 0.54] |
| f_est-scheduled least-squares FIR | 0.76 |
| Kalman oscillator + frequency gate, tuned | 0.80 |
| Kalman oscillator, tuned | 0.81 |
| Band-pass + extrapolation | 0.95 |
| BMFLC | 0.96 |
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

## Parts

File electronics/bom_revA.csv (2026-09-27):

Refs | Qty | Value | Symbol | Footprint | Manufacturer | MPN | Tolerance | Voltage | DNP | Board | Status | Notes
U22 | 1 | 74AUP1G74 | 74xGxx:74AUP1G74 | Package_SO:VSSOP-8_2.3x2mm_P0.5mm | Texas Instruments | SN74AUP1G74DCUR |  |  |  | main | VERIFY | PRE and CLR both low gives Q = ~Q = high: firmware clears only with ACT_EN_REQ low
U23 | 1 | 74LVC1G11 | 74xGxx:74LVC1G11 | Package_TO_SOT_SMD:SOT-363_SC-70-6 | Texas Instruments | SN74LVC1G11DCKR |  |  |  | main | OK
U14 U18 | 2 | INA241A1 | Amplifier_Current:INA241A1xDDF | Package_TO_SOT_SMD:SOT-23-8 | Texas Instruments | INA241A1IDDFR |  |  |  | main | VERIFY | G = 10 V/V; CM range and PWM transient recovery at 3-4.2 V VMOT; REF pin load on REF3012
U9 | 1 | ADS1220IPW | Analog_ADC:ADS1220xPW | Package_SO:TSSOP-16_4.4x5mm_P0.65mm | Texas Instruments | ADS1220IPWR |  |  | DNP | bench | OK
U3 | 1 | BQ29700 | Battery_Management:BQ297xy | Package_SON:WSON-6_1.5x1.5mm_P0.5mm | Texas Instruments | BQ29700DSER |  |  |  | main | VERIFY | variant thresholds (OVP/UVP/OCD) vs cell; X2SON/WSON package code
U2 | 1 | MCP73831-2-OT | Battery_Management:MCP73831-2-OT | Package_TO_SOT_SMD:SOT-23-5 | Microchip | MCP73831T-2ACI/OT |  |  |  | main | VERIFY | 4.20 V variant; charge current 1000/R_PROG[kohm] mA -> 147 mA (0.7 C of 200 mAh)
U15 U16 U19 U20 | 4 | LMV331 | Comparator:LMV331 | Package_TO_SOT_SMD:SOT-353_SC-70-5 | Texas Instruments | LMV331IDCKR |  |  |  | main | OK
J3 | 1 | TC2030-NL | Connector:Conn_ARM_SWD_TagConnect_TC2030-NL | Connector:Tag-Connect_TC2030-IDC-NL_2x03_P1.27mm_Vertical |  |  |  |  |  | main | VERIFY | pads only (zero height); needs 3 locating holes inside an 11.5 mm board
TP4 | 1 | +3V0 | Connector:TestPoint | TestPoint:TestPoint_Pad_D1.0mm |  |  |  |  |  | main | VERIFY
TP5 | 1 | +3V0A | Connector:TestPoint | TestPoint:TestPoint_Pad_D1.0mm |  |  |  |  |  | main | VERIFY
TP11 | 1 | AIN7_SPARE | Connector:TestPoint | TestPoint:TestPoint_Pad_D1.0mm |  |  |  |  |  | main | VERIFY
TP28 | 1 | ERM + | Connector:TestPoint | Connector_Wire:SolderWirePad_1x01_SMD_1x2mm |  |  |  |  |  | main | VERIFY
TP29 | 1 | ERM - | Connector:TestPoint | Connector_Wire:SolderWirePad_1x01_SMD_1x2mm |  |  |  |  |  | main | VERIFY
TP6 | 1 | GND | Connector:TestPoint | TestPoint:TestPoint_Pad_D1.0mm |  |  |  |  |  | main | VERIFY
TP8 | 1 | ISNS_X | Connector:TestPoint | TestPoint:TestPoint_Pad_D1.0mm |  |  |  |  |  | main | VERIFY
TP9 | 1 | ISNS_Y | Connector:TestPoint | TestPoint:TestPoint_Pad_D1.0mm |  |  |  |  |  | main | VERIFY
TP22 | 1 | NTC a | Connector:TestPoint | Connector_Wire:SolderWirePad_1x01_SMD_1x2mm |  |  |  |  |  | main | VERIFY
TP23 | 1 | NTC b | Connector:TestPoint | Connector_Wire:SolderWirePad_1x01_SMD_1x2mm |  |  |  |  |  | main | VERIFY
TP2 | 1 | UART_RX | Connector:TestPoint | TestPoint:TestPoint_Pad_D1.0mm |  |  |  |  |  | main | VERIFY
TP1 | 1 | UART_TX | Connector:TestPoint | TestPoint:TestPoint_Pad_D1.0mm |  |  |  |  |  | main | VERIFY
TP7 | 1 | VBAT | Connector:TestPoint | TestPoint:TestPoint_Pad_D1.0mm |  |  |  |  |  | main | VERIFY
TP3 | 1 | VMOT | Connector:TestPoint | TestPoint:TestPoint_Pad_D1.0mm |  |  |  |  |  | main | VERIFY
TP10 | 1 | VREF_1V25 | Connector:TestPoint | TestPoint:TestPoint_Pad_D1.0mm |  |  |  |  |  | main | VERIFY
TP20 | 1 | cell + | Connector:TestPoint | Connector_Wire:SolderWirePad_1x01_SMD_1x2mm |  |  |  |  |  | main | VERIFY
TP21 | 1 | cell - | Connector:TestPoint | Connector_Wire:SolderWirePad_1x01_SMD_1x2mm |  |  |  |  |  | main | VERIFY
TP24 | 1 | coil X + | Connector:TestPoint | Connector_Wire:SolderWirePad_1x01_SMD_1x2mm |  |  |  |  |  | main | VERIFY
TP25 | 1 | coil X - | Connector:TestPoint | Connector_Wire:SolderWirePad_1x01_SMD_1x2mm |  |  |  |  |  | main | VERIFY
TP26 | 1 | coil Y + | Connector:TestPoint | Connector_Wire:SolderWirePad_1x01_SMD_1x2mm |  |  |  |  |  | main | VERIFY
TP27 | 1 | coil Y - | Connector:TestPoint | Connector_Wire:SolderWirePad_1x01_SMD_1x2mm |  |  |  |  |  | main | VERIFY
J1 | 1 | USB-C receptacle (USB 2.0) | Connector:USB_C_Receptacle_USB2.0_16P | Connector_USB:USB_C_Receptacle_HRO_TYPE-C-31-M-12 | HRO | TYPE-C-31-M-12 |  |  |  | tail | VERIFY | mid-mount height vs 11 mm board width
J8 | 1 | strain bridge | Connector_Generic_MountingPin:Conn_01x04_MountingPin | Connector_JST:JST_SH_SM04B-SRSS-TB_1x04-1MP_P1.00mm_Horizontal |  |  |  |  | DNP | bench | VERIFY
J4 | 1 | optical module 1 | Connector_Generic_MountingPin:Conn_01x07_MountingPin | Connector_FFC-FPC:TE_0-1734839-7_1x07-1MP_P0.5mm_Horizontal |  |  |  |  |  | main | VERIFY | module interface pending sensor selection (EXP-S01); 3 modules at 30/150/270 deg, z = 14.2 mm
J5 | 1 | optical module 2 | Connector_Generic_MountingPin:Conn_01x07_MountingPin | Connector_FFC-FPC:TE_0-1734839-7_1x07-1MP_P0.5mm_Horizontal |  |  |  |  |  | main | VERIFY | module interface pending sensor selection (EXP-S01); 3 modules at 30/150/270 deg, z = 14.2 mm
J6 | 1 | optical module 3 | Connector_Generic_MountingPin:Conn_01x07_MountingPin | Connector_FFC-FPC:TE_0-1734839-7_1x07-1MP_P0.5mm_Horizontal |  |  |  |  |  | main | VERIFY | module interface pending sensor selection (EXP-S01); 3 modules at 30/150/270 deg, z = 14.2 mm
AE1 | 1 | 2450AT18A100 | Device:Antenna_Chip | RF_Antenna:Johanson_2450AT18x100 | Johanson Technology | 2450AT18A100E |  |  |  | main | VERIFY | keep-out and ground clearance in a 15 mm metal-free tail
C3 C7 C10 C13 C14 C15 C17 C18 C19 C21 C25 C26 C27 C31 C41 C42 C43 C45 C61 C62 C63 C65 C70 C71 C72 C73 C80 | 27 | 100n | Device:C | Capacitor_SMD:C_0402_1005Metric |  |  |  |  |  | hall_flex;main | GENERIC | Nordic ref.
C28 C29 C32 C33 | 4 | 100n | Device:C | Capacitor_SMD:C_0402_1005Metric |  |  |  |  | DNP | bench;hall_flex | GENERIC
C34 C44 C64 | 3 | 10n | Device:C | Capacitor_SMD:C_0402_1005Metric |  |  |  |  |  | main | GENERIC+VERIFY | C0G | C0G; 15.9 kHz anti-alias corner
C30 | 1 | 10n | Device:C | Capacitor_SMD:C_0402_1005Metric |  |  |  |  | DNP | bench | GENERIC+VERIFY | differential RC with bridge output resistance
C40 C60 | 2 | 10u | Device:C | Capacitor_SMD:C_0603_1608Metric |  |  |  | 6.3V |  | main | GENERIC
C8 C11 | 2 | 1n | Device:C | Capacitor_SMD:C_0402_1005Metric |  |  |  |  |  | main | GENERIC+VERIFY | REF3012 capacitive-load limit | sets VMOT slew; check inrush into 2 x 10 uF
C4 C5 C6 C9 C20 | 5 | 1u | Device:C | Capacitor_SMD:C_0402_1005Metric |  |  |  |  |  | main | GENERIC | Nordic ref.
C1 C2 C12 C16 | 4 | 4u7 | Device:C | Capacitor_SMD:C_0402_1005Metric |  |  |  | 10V |  | main | GENERIC | Nordic ref.
C23 C24 | 2 | DNP | Device:C | Capacitor_SMD:C_0402_1005Metric |  |  |  |  | DNP | main | GENERIC
C22 | 1 | RF match C | Device:C | Capacitor_SMD:C_0402_1005Metric |  |  |  |  |  | main | GENERIC+VERIFY | Nordic ref. matching value
Y2 | 1 | 32.768kHz | Device:Crystal | Crystal:Crystal_SMD_2012-2Pin_2.0x1.2mm |  |  |  |  |  | main | VERIFY | CL 7-9 pF (internal LFXO caps)
Y1 | 1 | 32MHz | Device:Crystal_GND24 | Crystal:Crystal_SMD_2016-4Pin_2.0x1.6mm |  |  |  |  |  | main | VERIFY | CL within nRF5340 internal HFXO load-cap range; +/-40 ppm total for BLE
D2 | 1 | Schottky 0.5A | Device:D_Schottky | Diode_SMD:D_SOD-523 |  |  |  |  |  | main | VERIFY
FB1 | 1 | 600R@100MHz | Device:FerriteBead | Inductor_SMD:L_0402_1005Metric |  |  |  |  |  | main | GENERIC+VERIFY | DCR <= 0.5 ohm at 30 mA
L1 | 1 | RF match L | Device:L | Inductor_SMD:L_0402_1005Metric |  |  |  |  |  | main | GENERIC+VERIFY | Nordic ref. matching value
D1 | 1 | green | Device:LED | LED_SMD:LED_0402_1005Metric |  |  |  |  |  | main | VERIFY
Q2 | 1 | NMOS 20V <=30mR@2.5V (CHG) | Device:Q_NMOS_GSD | Package_TO_SOT_SMD:SOT-23 |  |  |  |  |  | main | SELECT | SELECT: see Q1
Q1 | 1 | NMOS 20V <=30mR@2.5V (DSG) | Device:Q_NMOS_GSD | Package_TO_SOT_SMD:SOT-23 |  |  |  |  |  | main | SELECT | SELECT: common-drain dual NMOS in one package preferred
Q3 Q4 | 2 | NMOS logic-level | Device:Q_NMOS_GSD | Package_TO_SOT_SMD:SOT-723 |  |  |  |  |  | main | SELECT | SELECT: Vgs(th) < 1.0 V, Id >= 0.3 A | SELECT: Vgs(th) max < 1.2 V (CHG_DET high = 2.37 V min)
R11 R16 | 2 | 0R | Device:R | Resistor_SMD:R_0402_1005Metric |  |  |  |  |  | main | GENERIC+VERIFY | QOD-to-VOUT link; a resistor here slows output discharge | antenna pi-pad series; tune with VNA on assembled pen
R30 R50 | 2 | 0R1 | Device:R | Resistor_SMD:R_0603_1608Metric |  |  | 1% |  |  | main | GENERIC+VERIFY | sense shunt, <= 50 ppm/K
R18 R62 | 2 | 100 | Device:R | Resistor_SMD:R_0402_1005Metric |  |  |  |  |  | main | GENERIC+VERIFY | isolates SAADC sampling kick-back from the INA241 REF pins
R4 R5 R6 R63 R70 R71 R72 | 7 | 100k | Device:R | Resistor_SMD:R_0402_1005Metric |  |  |  |  |  | main | GENERIC
R14 R15 R17 R60 R73 R74 R75 R78 | 8 | 10k | Device:R | Resistor_SMD:R_0402_1005Metric |  |  |  |  |  | hall_flex;main | GENERIC
R31 R51 R61 | 3 | 1k | Device:R | Resistor_SMD:R_0402_1005Metric |  |  |  |  |  | main | GENERIC
R76 | 1 | 21k5 | Device:R | Resistor_SMD:R_0402_1005Metric |  |  | 1% |  |  | main | GENERIC
R8 | 1 | 2k2 | Device:R | Resistor_SMD:R_0402_1005Metric |  |  |  |  |  | main | GENERIC
R12 R13 | 2 | 33 | Device:R | Resistor_SMD:R_0402_1005Metric |  |  |  |  |  | main | GENERIC+VERIFY | series termination for 60 mm flex to optics; tune from SI check
R7 | 1 | 330 | Device:R | Resistor_SMD:R_0402_1005Metric |  |  |  |  |  | main | GENERIC
R9 R10 | 2 | 470k | Device:R | Resistor_SMD:R_0402_1005Metric |  |  | 0.5% |  |  | main | GENERIC
R77 | 1 | 56k | Device:R | Resistor_SMD:R_0402_1005Metric |  |  | 1% |  |  | main | GENERIC
R1 R2 | 2 | 5k1 | Device:R | Resistor_SMD:R_0402_1005Metric |  |  | 1% |  |  | tail | GENERIC
R3 | 1 | 6k8 | Device:R | Resistor_SMD:R_0402_1005Metric |  |  | 1% |  |  | main | GENERIC
U13 U17 | 2 | DRV8212PDSG | Driver_Motor:DRV8212P | Package_SON:WSON-8-1EP_2x2mm_P0.5mm_EP0.9x1.6mm_ThermalVias | Texas Instruments | DRV8212PDSGR |  |  |  | main | VERIFY | Rds(on) HS+LS, PWM frequency limit, input pull-downs, OCP threshold
U7 | 1 | nRF5340-QKAA | MCU_Nordic:nRF5340-QKxx | Package_DFN_QFN:Nordic_AQFN-94-1EP_7x7mm_P0.4mm | Nordic Semiconductor | NRF5340-QKAA-R7 |  |  |  | main | VERIFY | decoupling values and DEC-pin wiring against nRF5340 PS reference circuitry (LDO-only, normal voltage mode); P0.02/P0.03 as GPIO need UICR.NFCPINS = 0
U21 | 1 | W25Q128JVPIQ | Memory_Flash:W25Q128JVP | Package_SON:WSON-8-1EP_6x5mm_P1.27mm_EP3.4x4.3mm | Winbond | W25Q128JVPIQ |  |  |  | main | VERIFY | QE bit default for quad mode; 2.7 V minimum VCC
U5 | 1 | TPS22917DBV | Power_Management:TPS22917DBV | Package_TO_SOT_SMD:SOT-23-6 | Texas Instruments | TPS22917DBVR |  |  |  | main | VERIFY | 2 A continuous, Ron ~80 mOhm at 3.6 V; QOD to VOUT = fastest discharge
U1 | 1 | USBLC6-2P6 | Power_Protection:USBLC6-2P6 | Package_TO_SOT_SMD:SOT-666 | STMicroelectronics | USBLC6-2P6 |  |  |  | tail | OK
U6 | 1 | REF3012 | Reference_Voltage:REF3012 | Package_TO_SOT_SMD:SOT-23 | Texas Instruments | REF3012AIDBZR |  |  |  | main | VERIFY | output capacitor range for stability; load = 2 x INA241 REF + SAADC input
U4 | 1 | TLV75530PDBV | Regulator_Linear:TLV75530PDBV | Package_TO_SOT_SMD:SOT-23-5 | Texas Instruments | TLV75530PDBVR |  |  |  | main | OK
U11 U12 | 2 | DRV5055A1 | Sensor_Magnetic:DRV5055A1xDBZxQ1 | Package_TO_SOT_SMD:SOT-23 |  |  |  |  | DNP | hall_flex | VERIFY | ratiometric; 3.0 V supply below 3.3 V min? check
U10 | 1 | TMAG5170A1 | Sensor_Magnetic:TMAG5170-Q1 | Package_SO:VSSOP-8_3x3mm_P0.65mm | Texas Instruments | TMAG5170A1QDGKR |  |  |  | hall_flex | VERIFY | range variant (A1 +/-25..100 mT vs A2) from magnet field map; TEST pin handling; mounted on tail flex
U8 | 1 | LSM6DSV16X | Sensor_Motion:LSM6DSM | Package_LGA:LGA-14_3x2.5mm_P0.5mm_LayoutBorder3x4y | STMicroelectronics | LSM6DSV16XTR |  |  |  | main | VERIFY | LSM6DSM symbol used as LGA-14 placeholder: confirm LSM6DSV16X pins 2, 3, 10, 11 functions and unused-pin handling
SW1 | 1 | mode button | Switch:SW_Push | Button_Switch_SMD:SW_Push_1P1T_NO_CK_KMR2 |  |  |  |  |  | main | VERIFY

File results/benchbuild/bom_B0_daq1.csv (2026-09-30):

build | line | kind | item | manufacturer | part_number | supplier | supplier_pn | qty | unit_price_seen | currency | unit_usd_low | unit_usd_high | line_usd_low | line_usd_high | price_label | price_source | seen | availability | lead_time | ledger | fabrication_source | material | process | tolerance_finish | who | stage | mvp | optional_if_lab_has_it | notes
B0 | 1 | purchased | Microcontroller board Teensy 4.1 (DAQ-1 and a spare) | PJRC | Teensy 4.1 | SparkFun | DEV-16771 | 2 | 31.5 | USD | 31.5 | 31.5 | 63 | 63 | MANUFACTURER | https://www.sparkfun.com/teensy-4-1.html | 2026-09-30 | In stock | 1-5 days (in stock) | AMF-220 (re-seen 2026-09-30) |  |  |  |  | hobbyist | S0 | Y | N | 600 MHz cycle counter is the time base (docs/measurement_rig.md s1.3)
B0 | 2 | purchased | 24-bit 8-channel simultaneous ADC evaluation module (EVM, PHI controller, USB cable) | Texas Instruments | ADS131M08EVM | DigiKey | 296-ADS131M08EVM-ND | 1 | 328.11 | USD | 328.11 | 328.11 | 328 | 328 | MANUFACTURER | https://www.digikey.com/en/products/result?keywords=ADS131M08EVM | 2026-09-30 | 2 in stock (DigiKey); TI page 'In stock', price after login | 1-5 days (in stock) | AMF-300 |  |  |  |  | hobbyist | S0 | Y | N | the PHI board is not used: J10 wired to the Teensy, AVDD/DVDD per SBAU334A (AMF-222); a second EVM only if R9 and R12 run at the same time
B0 | 3 | purchased | Thermocouple amplifier breakout MAX31856 | Adafruit | 3263 | Adafruit | 3263 | 4 | 17.5 | USD | 17.5 | 17.5 | 70 | 70 | MANUFACTURER | https://www.adafruit.com/product/3263 | 2026-09-30 | In stock | 1-5 days | AMF-234 (re-seen 2026-09-30) |  |  |  |  | hobbyist | S0 | Y | N
B0 | 4 | purchased | Type-T fine-wire thermocouples, 0.08 mm class (calibrate in a dry block, +-0.5 C) | class (e.g. Omega 5TC series) | type T, 40 AWG class | instrument distributor |  | 8 |  | USD | 15 | 40 | 120 | 320 | ASSUMPTION | omega.com returned HTTP 403 on 2026-09-30: price not seen |  |  | 1-2 weeks (ASSUMPTION) |  |  |  |  |  | hobbyist | S0 | Y | N
B0 | 5 | purchased | Current-sense resistor 0.1 ohm +-0.1 % 1 W, 4-terminal metal foil (2512) | VPG Foil Resistors | Y14870R10000B9R | DigiKey | 804-1045-1-ND | 4 | 13.05 | USD | 13.05 | 13.05 | 52 | 52 | MANUFACTURER | https://www.digikey.com/en/products/result?keywords=Y14870R10000B9R | 2026-09-30 | 0 in stock; 1,000 expected 12-Oct-2026 | about 2 weeks | AMF-303 |  |  |  |  | hobbyist | S0 | Y | N | coil and voice-coil currents on ADC channels (CHANNEL_MAPS)
B0 | 6 | purchased | Linear power op-amp for current drive (voice coils, coupon coils), TO-220-7 | Texas Instruments | OPA548T | DigiKey | product 266166 | 2 | 21.55 | USD | 21.55 | 21.55 | 43 | 43 | MANUFACTURER | https://www.digikey.com/en/products/detail/texas-instruments/OPA548T/266166 | 2026-09-30 | 0 in stock, 50 expected 30-Nov-2026 (DigiKey); TI store: out of stock | >= 9 weeks (back-order) | AMF-301 |  |  |  |  | hobbyist | S1 | N | N | LEAD-TIME RISK. Fallbacks: OPA564AIDWP (1.5 A, DigiKey USD 9.51, stock not shown, AMF-301) on a small board; or Pololu 4035 DRV8874 (AMF-305) at >= 40 kHz with an output LC filter for the R9 voice coil; OPA549T also back-ordered (02-Dec-2027)
B0 | 7 | purchased | 12 V 60 W desktop supply (driver and excitation rails) | Mean Well | GST60A12-P1J | DigiKey | product 7703712 | 1 | 19.4 | USD | 19.4 | 19.4 | 19 | 19 | MANUFACTURER | https://www.digikey.com/en/products/result?keywords=GST60A12-P1J | 2026-09-30 | in stock (Normally Stocking) | 1-5 days | AMF-308 |  |  |  |  | hobbyist | S0 | Y | N
B0 | 8 | purchased | Wiring kit: headers, JST/Dupont, shielded 12-core cable, perfboard, RC filters, 10 ohm/10 uF excitation filter | class | - | any electronics distributor |  | 1 |  | USD | 60 | 150 | 60 | 150 | ASSUMPTION | lot of commodity parts, not priced line by line |  |  | 1 week |  |  |  |  |  | hobbyist | S0 | Y | N
B0 | 9 | fabricated | DAQ-1 enclosure and connector panel | - | PROPOSED DESIGN (no CAD) | in-house |  | 1 |  | USD | 10 | 40 | 10 | 40 | ASSUMPTION | 3-D print filament and hardware |  |  | 1-3 days |  | none (make to fit the EVM and Teensy) | PETG or laser-cut acrylic | FDM 3-D print / laser cut | +-0.3 mm | hobbyist | S0 | Y | N
B0 | 10 | instrument | Oscilloscope 4 ch 70 MHz (bring-up loop-backs, trigger and strobe timing) | Rigol | DHO804 | DigiKey | 2211-DHO804-ND | 1 | 459.0 | USD | 459.0 | 459.0 | 459 | 459 | MANUFACTURER | https://www.digikey.com/en/products/result?keywords=DHO804 | 2026-09-30 | 40 in stock | 1-5 days | AMF-321 |  |  |  |  | hobbyist | S0 | N | Y
B0 | 11 | instrument | 6.5-digit DMM with 4-wire resistance (wire, coil and shunt resistance) | Siglent | SDM3065X | DigiKey | product 10455229 | 1 | 857.0 | USD | 857.0 | 857.0 | 857 | 857 | MANUFACTURER | https://www.digikey.com/en/products/result?keywords=SDM3065X | 2026-09-30 | stock not shown | 1-2 weeks (ASSUMPTION) | AMF-322 |  |  |  |  | hobbyist | S0 | N | Y
B0 | 12 | instrument | Dual linear bench supply 0-30 V (+-15 V for the OPA548 stage) | class | - | any |  | 1 |  | USD | 150 | 450 | 150 | 450 | ASSUMPTION | not priced here |  |  | 1 week |  |  |  |  |  | hobbyist | S0 | N | Y
B0 | 13 | tool | Temperature-controlled soldering station | class | - | any |  | 1 |  | USD | 100 | 250 | 100 | 250 | ASSUMPTION | not priced here |  |  | 1 week |  |  |  |  |  | hobbyist | S0 | Y | Y
B0 | 14 | tool | Bench fume absorber (soldering; beryllium-copper joints under local exhaust, DEC-097 proposed) | Hakko | FA400-04 | DigiKey | product 6228795 | 1 | 93.79 | USD | 93.79 | 93.79 | 94 | 94 | MANUFACTURER | https://www.digikey.com/en/products/result?keywords=FA400-04 | 2026-09-30 | stock not shown | 1-2 weeks (ASSUMPTION) | AMF-317 |  |  |  |  | hobbyist | S0 | Y | N
B0 | 15 | tool | Hand tools: calipers 0.01 mm, micrometer 0.001 mm, ESD mat, tweezers, flush cutters, loupe | class | - | any |  | 1 |  | USD | 150 | 400 | 150 | 400 | ASSUMPTION | not priced here |  |  | 1 week |  |  |  |  |  | hobbyist | S0 | Y | Y

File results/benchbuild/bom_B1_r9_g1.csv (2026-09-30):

build | line | kind | item | manufacturer | part_number | supplier | supplier_pn | qty | unit_price_seen | currency | unit_usd_low | unit_usd_high | line_usd_low | line_usd_high | price_label | price_source | seen | availability | lead_time | ledger | fabrication_source | material | process | tolerance_finish | who | stage | mvp | optional_if_lab_has_it | notes
B1 | 1 | purchased | CoreXY printer kit as the motion frame (head moves in x-y, bed only in z; chamber to 55 C) | Prusa Research | Prusa CORE One+ (Gen 2) assembly kit | prusa3d.com | - | 1 | 925.0 | USD | 925.0 | 925.0 | 925 | 925 | MANUFACTURER | https://www.prusa3d.com/product/prusa-core-one/ | 2026-09-30 | In stock. Preparation time: 1-3 business days | 1-2 weeks incl. shipping (shipping ASSUMPTION) | AMF-231 (re-seen 2026-09-30) |  |  |  |  | hobbyist | S0 | Y | N | assembled USD 1,202.78 on the same page; hotend and bed heaters disconnected; payload of the 190 g head checked (EXP-BB02)
B1 | 2 | instrument | 3-axis force sensor +-2 N under the paper (N and friction in the page frame) | ME-Messsysteme | K3D40 +-2N | me-systeme.de (quote) |  | 1 |  | USD | 900 | 1900 | 900 | 1900 | ASSUMPTION | price behind a login (me-systeme.de HTTP 403; pm-instrumentation.com 'Log in to view prices'), 2026-09-30 |  |  | 2-6 weeks (ASSUMPTION; order day 1) | AMF-224 |  |  |  |  | supplier | S0 | Y | N
B1 | 3 | instrument | 3-axis force sensor +-10 N (N and friction above the +-2 N plate's range; R12 force map; five-bar force capacity) | ME-Messsysteme | K3D40 +-10N | me-systeme.de (quote) |  | 1 |  | USD | 900 | 1900 | 900 | 1900 | ASSUMPTION | as line 2 |  |  | 2-6 weeks (ASSUMPTION) | AMF-224 |  |  |  |  | supplier | S1 | N | N
B1 | 4 | instrument | In-line axial load cell 100 g (1 N), 2 mV/V | FUTEK | LSB200 FSH03870 | futek.com (quote) |  | 1 |  | USD | 450 | 900 | 450 | 900 | ASSUMPTION | FUTEK store page shows $0.00 (price not displayed), 2026-09-30 |  |  | 1-4 weeks (ASSUMPTION) | AMF-225 |  |  |  |  | supplier | S0 | Y | N
B1 | 5 | purchased | Voice coil for F_c ramps and modulation (current mode) | Moticont | LVCM-013-013-03 | moticont.com (quote) |  | 1 |  | USD | 150 | 350 | 150 | 350 | ASSUMPTION | product page lists specifications, no price (2026-09-30) |  |  | 2-6 weeks (ASSUMPTION) | AMF-02 |  |  |  |  | supplier | S1 | N | N | MVP: dead weights on a thread over a jewel-bearing pulley (fixed F_c levels, docs/measurement_rig.md s2.9)
B1 | 6 | instrument | Linear magnetic encoder LM13, 13B resolution, with MS scale (per axis) | RLS | LM13 (13B) | RLS / Renishaw distributor (quote) |  | 2 |  | USD | 250 | 700 | 500 | 1400 | ASSUMPTION | no price published (OPT-89) |  |  | 2-6 weeks (ASSUMPTION) | OPT-89 |  |  |  |  | supplier | S1 | N | N | MVP: stroke timing from the printer's move start (marker input, pin 32) and the commanded speed; LM13 needed for R10 per-sample truth
B1 | 7 | purchased | Linear Hall sensor for the cartridge slide | Texas Instruments | DRV5055A4QDBZR | DigiKey | 296-50468-1-ND | 4 | 0.87 | USD | 0.87 | 0.87 | 3 | 3 | MANUFACTURER | https://www.digikey.com/en/products/result?keywords=DRV5055A4QDBZR | 2026-09-30 | 3,538 in stock | 1-5 days | AMF-302 |  |  |  |  | hobbyist | S0 | Y | N
B1 | 8 | purchased | Slide target magnet, N52, about 2 mm | class | - | magnet retailer |  | 4 |  | USD | 0.5 | 3 | 2 | 12 | ASSUMPTION | commodity |  |  | 1 week |  |  |  |  |  | hobbyist | S0 | Y | N
B1 | 9 | consumable | Refills: Schmidt S 635 M x20, easyFLOW 9000 x10, P 8126 x10, FL 6040 F x10; a second D1 oil brand x10 and a gel D1 x10 (study B's EXP-B20 set) | Schmidt Technology; class | as listed | stationery distributors |  | 1 |  | USD | 70 | 360 | 70 | 360 | ASSUMPTION | prices not seen (CON-100) |  |  | 1-2 weeks | CON-100 |  |  |  |  | hobbyist | S0 | Y | N | log brand and lot
B1 | 10 | consumable | Six papers (copy 80 g/m2, recycled, school ruled, coated, tracing, card), one pack each | class | - | stationery |  | 1 |  | USD | 60 | 150 | 60 | 150 | ASSUMPTION | commodity |  |  | 1 week |  |  |  |  |  | hobbyist | S0 | Y | N | condition 24 h at 23 C / 50 % RH
B1 | 11 | instrument | Calibration weight set OIML M1, 1 g-500 g (12 pieces) | Mettler Toledo | 30402728 | Scales Galore | px60692 | 1 | 535.5 | USD | 535.5 | 535.5 | 536 | 536 | MANUFACTURER | https://www.scalesgalore.com/product/Mettler-Toledo-30402728-OIML-Class-M1-Stainless-Steel-Calibration-Weight-Set-1-g-to-500-g-px60692.cfm | 2026-09-30 | Available to Ship | 1-2 weeks (ASSUMPTION) | AMF-315 |  |  |  |  | hobbyist | S0 | Y | N | in-situ calibration at every test angle; also the MVP's dead-weight F_c
B1 | 12 | purchased | Jewel-bearing pulley and thread (horizontal pulls; dead-weight F_c) | class | - | any |  | 1 |  | USD | 20 | 80 | 20 | 80 | ASSUMPTION | not priced here |  |  | 1-2 weeks |  |  |  |  |  | hobbyist | S0 | Y | N
B1 | 13 | instrument | Digital inclinometer 0.1 deg class (tilt under load) | class | - | any |  | 1 |  | USD | 30 | 120 | 30 | 120 | ASSUMPTION | not priced here |  |  | 1 week |  |  |  |  |  | hobbyist | S0 | Y | N
B1 | 14 | consumable | Spring-steel shim 0.05 mm (guide leaves) | class | - | any |  | 1 |  | USD | 20 | 60 | 20 | 60 | ASSUMPTION | not priced here |  |  | 1 week |  |  |  |  |  | hobbyist | S0 | Y | N
B1 | 15 | instrument | Flatbed scanner 4800 dpi optical (gap fractions for EXP-T02) | Epson | Perfection V39 II (B11B268201) | epson.com | B11B268201 | 1 | 129.99 | USD | 129.99 | 129.99 | 130 | 130 | MANUFACTURER | https://www.epson.com/For-Work/Scanners/Photo-and-Graphics/Epson-Perfection-V39-II-Color-Photo-and-Document-Scanner/p/B11B268201 | 2026-09-30 | 'Add to Cart' shown | 1-2 weeks | AMF-314 |  |  |  |  | hobbyist | S0 | Y | N | R3's 5 um (k=2) ink-path metrology for G3 needs the V850 Pro (USD 1,999, AMF-236) or a microscope: deferred
B1 | 16 | instrument | USAF-1951 resolution target (scanner check before gap fractions) | class | - | optics retailer |  | 1 |  | USD | 50 | 200 | 50 | 200 | ASSUMPTION | not priced here |  |  | 1-2 weeks |  |  |  |  |  | hobbyist | S0 | Y | N
B1 | 17 | consumable | Underlays (1 mm float glass, 10-sheet pad, 1 mm elastomer) and 1.5 mm CFRP sheet | class | - | any |  | 1 |  | USD | 30 | 100 | 30 | 100 | ASSUMPTION | not priced here |  |  | 1 week |  |  |  |  |  | hobbyist | S0 | Y | N
B1 | 18 | purchased | Fasteners, dowel pins, M3 kit | class | - | any |  | 1 |  | USD | 30 | 80 | 30 | 80 | ASSUMPTION | not priced here |  |  | 1 week |  |  |  |  |  | hobbyist | S0 | Y | N
B1 | 19 | fabricated | Tilt arc R70 (35/50/65/75 deg holes) and arc carriage: printed MVP version | - | arc_frame, arc_carriage | in-house |  | 1 |  | USD | 10 | 40 | 10 | 40 | ASSUMPTION | filament |  |  | 1-3 days |  | results/rig/cad/rig_contact_assembly.step (arc_frame, arc_carriage) | PETG or PA-CF | FDM 3-D print | +-0.2 mm; tilt set and checked under load with the inclinometer | hobbyist | S0 | Y | N | replace by the CNC version (line 20) if the tilt drifts by > 0.1 deg under load
B1 | 20 | fabricated | Tilt arc R70 and arc carriage: CNC version | - | arc_frame, arc_carriage | machine shop |  | 1 |  | USD | 150 | 600 | 150 | 600 | ASSUMPTION | one-off CNC quote range |  |  | 1-3 weeks |  | results/rig/cad/rig_contact_assembly.step (arc_frame, arc_carriage) | 6061-T6 | CNC milling | hole pattern +-0.05 mm; arc radius +-0.05 mm | shop | S1 | N | N | bead blast; anodise optional
B1 | 21 | fabricated | Cartridge frame with leaf clamps, refill holder/collet (D1 2.35 mm; G2 6 mm), Hall bracket | - | cartridge_frame, holder, hall_bracket | machine shop |  | 1 |  | USD | 150 | 500 | 150 | 500 | ASSUMPTION | one-off CNC/lathe quote range |  |  | 1-3 weeks |  | results/rig/cad/rig_contact_assembly.step (cartridge_frame, holder, hall_bracket) | 6061-T6; brass collet; printed bracket | CNC milling, lathe; FDM for the bracket | +-0.02 mm on the leaf clamp faces; holder bore 2.4 H7 | shop | S0 | Y | N | the axial path must be straight: closure check AC-T01-01
B1 | 22 | fabricated | Guide leaves 0.05 x 8 x 25 mm (x2) | - | guide_leaves | in-house |  | 2 |  | USD | 0 | 25 | 0 | 50 | ASSUMPTION | from the shim of line 14 |  |  | 1 day |  | results/rig/cad/rig_contact_assembly.step (guide_leaves) | spring steel shim 0.05 mm | shear or scalpel against a template, deburr; or photo-etch | +-0.05 mm, flat, no kinks | hobbyist | S0 | Y | N
B1 | 23 | fabricated | Bed adapter 120 x 100 x 6 mm and head plate to the CORE One carriage | - | bed_adapter; head plate | machine shop |  | 1 |  | USD | 100 | 350 | 100 | 350 | ASSUMPTION | one-off CNC quote range |  |  | 1-3 weeks |  | results/rig/cad/rig_contact_assembly.step (bed_adapter); head plate from the CORE One's published CAD | 6061-T6 | CNC milling | flatness 0.05 mm; K3D40 M3 pattern +-0.05 mm | shop | S0 | Y | N
B1 | 24 | fabricated | CFRP platen 80 x 60 x 1.5 mm and paper edge clamps | - | platen_cfrp, clamp_nx, clamp_px | supplier cut + in-house clamps |  | 1 |  | USD | 20 | 100 | 20 | 100 | ASSUMPTION | waterjet/CNC of a CFRP sheet by a supplier (dust) |  |  | 1-2 weeks |  | results/rig/cad/rig_contact_assembly.step (platen_cfrp, clamp_nx, clamp_px) | CFRP 1.5 mm; PETG clamps | waterjet or CNC routing (supplier, dust extraction); FDM | +-0.2 mm | supplier | S0 | Y | N
B1 | 25 | instrument | In-line axial load cell 250 g (2.5 N): N up to 2 N at every tilt (AC-B01-20's envelope) and G2-format refills | FUTEK | LSB200 FSH03871 | futek.com (quote) |  | 1 |  | USD | 450 | 900 | 450 | 900 | ASSUMPTION | price not displayed (as line 4) |  |  | 1-4 weeks (ASSUMPTION) | AMF-225 |  |  |  |  | supplier | S1 | N | N | the rig design uses the 100 g cell for F_c <= 0.5 N and the 250 g cell above (docs/measurement_rig.md s2.2); EXP-B01's 4 N level needs a larger cell still (prototype_stages.md s0 open item; bench_calcs.json r9_normal_force_reach)

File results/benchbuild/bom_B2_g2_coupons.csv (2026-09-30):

build | line | kind | item | manufacturer | part_number | supplier | supplier_pn | qty | unit_price_seen | currency | unit_usd_low | unit_usd_high | line_usd_low | line_usd_high | price_label | price_source | seen | availability | lead_time | ledger | fabrication_source | material | process | tolerance_finish | who | stage | mvp | optional_if_lab_has_it | notes
B2 | 1 | purchased | N52 block magnets 5 x 5 x 3 mm (+-0.1 mm), magnetised through 3 mm: stock stand-in for Rev K's 5.12 x 5.12 x 3.5 mm poles | Webcraft GmbH (supermagnete) | Q-05-05-03-N52N | supermagnete.de | Q-05-05-03-N52N | 20 | 0.35 | EUR | 0.37 | 0.44 | 7 | 9 | MANUFACTURER | https://www.supermagnete.de/eng/block-magnets-neodymium/block-magnet-5mm-5mm-3mm_Q-05-05-03-N52N | 2026-09-30 | 2,120 pieces in stock; 1-3 business days | 1-2 weeks incl. shipping | AMF-309 |  |  |  |  | hobbyist | S2 | N | N | EUR 0.35 each at 20+ incl. VAT; predictions re-run at the as-built size (bench_protocols.md s0.2)
B2 | 2 | purchased | N52 cube magnets 4.76 mm (+-0.1 mm): stock stand-in for the reach candidate's 4.81 mm poles | K&J Magnetics | B333-N52 | kjmagnetics.com | B333-N52 | 12 | 0.56 | USD | 0.56 | 0.56 | 7 | 7 | MANUFACTURER | https://www.kjmagnetics.com/b333-n52-neodymium-block-magnet | 2026-09-30 | In Stock | 1-2 weeks | AMF-310 |  |  |  |  | hobbyist | S2 | N | N | Br 14,800 G on the page; 1.26 mm thicker than the 3.5 mm design pole
B2 | 3 | purchased | Custom N52 poles 4.81 x 4.81 x 3.5 mm and 5.12 x 5.12 x 3.5 mm (8 of each), after AC-T07-02 passes on stock magnets | custom magnet maker | to drawing | magnet supplier (quote) |  | 1 |  | USD | 150 | 600 | 150 | 600 | ASSUMPTION | custom batch, not quoted |  |  | 4-8 weeks (ASSUMPTION) |  |  |  |  |  | supplier | S2b | N | N | deferred (DEC-095 proposed)
B2 | 4 | fabricated | Back iron 0.5 mm and keeper 0.3 mm rings (reach: R 10.6/3.6 mm); Rev K back plate and keeper, and the heel variant's 1.2 mm notched pair | - | back_iron, keeper_with_front_race_surface; back_plate, keeper | laser/EDM service |  | 1 |  | USD | 60 | 300 | 60 | 300 | ASSUMPTION | small laser or wire-EDM batch |  |  | 1-3 weeks |  | results/improvement/mechanics/extended_reach_nib.step (back_iron, keeper_with_front_race_surface); results/revK/revK_pen_assembly.step (back_plate, keeper) | low-carbon steel 1008/1010 sheet | wire EDM or fibre-laser cut, deburr, stress relieve | +-0.02 mm; flatness 0.02 mm | shop | S2 | N | N
B2 | 5 | service | Racetrack coil packs, bonded: 0.8 mm per layer, bundles 2.2 mm wide, rows 4.75 mm (reach) or 5.0 mm (Rev K) off axis, xy order; 2-4 sets | - | winding_pack_0/1_+-1; coil_x, coil_y | coil-winding service (quote) |  | 1 |  | USD | 300 | 1500 | 300 | 1500 | ASSUMPTION | prototype coil sets not quoted |  |  | 3-6 weeks (ASSUMPTION) |  | results/improvement/mechanics/extended_reach_nib.step (winding_pack_*); results/revK/revK_pen_assembly.step (coil_x, coil_y) | self-bonding enamelled copper wire | wound on a split mandrel, heat or solvent bonded | layer thickness +-0.03 mm; outer corner inside the bore rule | supplier | S2 | N | N | in-house alternative: hand winding with bondable wire (line 6), skilled hobbyist; record turns, R20 and L
B2 | 6 | consumable | Self-bonding magnet wire 0.10-0.14 mm (in-house winding) | class | - | wire distributor |  | 1 |  | USD | 20 | 60 | 20 | 60 | ASSUMPTION | not priced here |  |  | 1-2 weeks |  |  |  |  |  | hobbyist | S2 | N | N
B2 | 7 | fabricated | Translation-coupon stator block (magnets at the 0.3 mm coil gap, 0.15 mm keeper spacer) and coil arm through the keeper hole | - | stator_plate, coupon_arm, base_plate, bridge | machine shop |  | 1 |  | USD | 200 | 700 | 200 | 700 | ASSUMPTION | one-off CNC quote range |  |  | 1-3 weeks |  | results/rig/cad/rig_coupon_assembly.step (base_plate, bridge, stator_plate, coupon_arm; goniometers locked for translation coupons) | 6061-T6; PEEK or resin arm | CNC milling; SLA print for the arm | +-0.02 mm on gap-setting faces; coil centred on the pole pattern within 0.05 mm | shop | S2 | N | N
B2 | 8 | instrument | Manual XYZ stage, 13-25 mm travel, 10 um graduation (coil position grid) | class (Thorlabs PT3/M class) | - | optics retailer |  | 1 |  | USD | 400 | 1600 | 400 | 1600 | ASSUMPTION | Thorlabs product pages are script-rendered and showed no price here; not seen |  |  | 1-3 weeks |  |  |  |  |  | hobbyist | S2 | N | N
B2 | 9 | instrument | LCR meter (coil inductance 100 Hz-10 kHz) | class | - | any |  | 1 |  | USD | 100 | 600 | 100 | 600 | ASSUMPTION | not priced here |  |  | 1-2 weeks |  |  |  |  |  | hobbyist | S2 | N | Y
B2 | 10 | purchased | C17200 (CuBe2) wire 0.10 mm and 0.08 mm, ordered age-hardened (DEC-097 proposed) | Goodfellow | Cu98/Be2 wire (code per diameter) | goodfellow.com | - | 2 | 279.0 | USD | 279.0 | 279.0 | 558 | 558 | MANUFACTURER | https://www.goodfellow.com/usa/copper-beryllium-alloy-spooled-wire-cu98-be2-group | 2026-09-30 | 'Starting at $279.00 each' (spooled); approximate lead time 2 weeks; diameters not displayed statically | about 2 weeks | AMF-311 |  |  |  |  | supplier | S2 | N | N | straight 1 m hard wire from USD 429.00 on the sister page; CONFIRM 0.10 mm and an aged temper (TH04/HT or AT) before ordering
B2 | 11 | fabricated | Wire clamp blocks (0.12 mm solder slot, 0.1 mm exit edge radius) x24, and crimp tubes | - | PROPOSED DESIGN (no CAD) | machine shop |  | 1 |  | USD | 200 | 700 | 200 | 700 | ASSUMPTION | one-off precision batch |  |  | 2-4 weeks |  |  | C360 brass (solder clamps); 304 hypodermic tube (crimp) | CNC + wire-EDM slot; exit radius polished before the wire goes in | slot +-0.01 mm; exit radius 0.10 +-0.02 mm (sets Kt) | shop | S2 | N | N
B2 | 12 | fabricated | Multi-coupon fatigue shuttle: crank-eccentric drive (stroke 1.26 or 1.7 mm), parallel-leaf guided shuttle, >= 6 coupon stations, guard | - | PROPOSED DESIGN (no CAD) | machine shop |  | 1 |  | USD | 300 | 1200 | 300 | 1200 | ASSUMPTION | one-off |  |  | 2-4 weeks |  |  | 6061-T6; spring-steel leaves; steel eccentric | CNC; ground eccentric pin | eccentricity +-0.01 mm; shuttle straightness 0.02 mm | shop | S2 | N | N | drive <= 0.2 x the coupon's measured first mode (DEC-098 proposed); balanced crank; guard (pinch point)
B2 | 13 | purchased | Shuttle drive motor and speed controller (3,600-9,000 rpm) | class | - | any |  | 1 |  | USD | 40 | 200 | 40 | 200 | ASSUMPTION | not priced here |  |  | 1-2 weeks |  |  |  |  |  | hobbyist | S2 | N | N
B2 | 14 | purchased | Eight-channel constant-current source 0.10-0.16 A with 4-wire sense leads to the ADS131M08 | class | PROPOSED DESIGN | parts from any distributor |  | 1 |  | USD | 30 | 100 | 30 | 100 | ASSUMPTION | commodity parts |  |  | 1-2 weeks |  |  |  |  |  | hobbyist | S2 | N | N
B2 | 15 | instrument | Laser displacement sensor, 30 mm (shuttle amplitude; wire first mode) | Panasonic | HG-C1030 | DigiKey | product 5215054 | 1 | 439.6 | USD | 439.6 | 439.6 | 440 | 440 | MANUFACTURER | https://www.digikey.com/en/products/detail/panasonic-industry/HG-C1030/5215054 | 2026-09-30 | 26 in stock; response time 1.5 ms | 1-5 days | AMF-318 |  |  |  |  | hobbyist | S2 | N | Y | the strobed OV9281 camera (B4) can replace it for the first mode
B2 | 16 | instrument | Stereo microscope >= 50x with camera (wire and clamp inspection) | class | - | any |  | 1 |  | USD | 300 | 1500 | 300 | 1500 | ASSUMPTION | not priced here |  |  | 1-2 weeks |  |  |  |  |  | hobbyist | S2 | N | Y
B2 | 17 | consumable | SnAgCu solder, flux for copper alloys, IPA wipes, sealable labelled waste bags | class | - | any |  | 1 |  | USD | 30 | 80 | 30 | 80 | ASSUMPTION | not priced here |  |  | 1 week |  |  |  |  |  | hobbyist | S2 | N | N
B2 | 18 | fabricated | Scaled Kt coupons: 1.0 mm C17200 wire in 10x clamps with 0.2 mm-grid strain gauges (Kt is geometric) | - | PROPOSED DESIGN | in-house + shop |  | 1 |  | USD | 150 | 400 | 150 | 400 | ASSUMPTION | gauges, wire and clamps |  |  | 2-3 weeks |  |  |  |  |  | shop | S2 | N | N | a strain gauge cannot be bonded on a 0.10 mm wire; open item for the lead (Kt method)
B2 | 19 | purchased | Si3N4 balls 0.8 mm, grade 5 | class (Ortech Ceramics lists 0.8 mm) | - | ceramic-ball supplier |  | 100 |  | USD | 0.2 | 0.8 | 20 | 80 | ASSUMPTION | prices not displayed (Ortech: quote; retail listings not opened) |  |  | 1-3 weeks |  |  |  |  |  | hobbyist | S2 | N | N
B2 | 20 | fabricated | Lapped 440C races: Rev K (16.6 mm ball circle, 2.26 mm wide) x3; reach (15.1 mm circle, 2.9 mm wide) x3; flange race inserts x4 | - | front_race, rear_race; rear_race, keeper_with_front_race_surface | precision grinding shop |  | 1 |  | USD | 400 | 1500 | 400 | 1500 | ASSUMPTION | one-off hardened, ground and lapped batch |  |  | 3-6 weeks (ASSUMPTION) |  | results/revK/revK_pen_assembly.step (front_race, rear_race); results/improvement/mechanics/extended_reach_nib.step (rear_race, keeper_with_front_race_surface) | 440C stainless | turn, harden and temper (HRC 58-60, ASSUMPTION), grind, lap | flatness <= 1 um; parallelism <= 2 um; Ra <= 0.05 um (ASSUMPTION spec) | shop | S2 | N | N
B2 | 21 | fabricated | Carrier flanges: Rev K 18.9 x 1.5 mm and reach 18 x 1.5 mm; one with 440C race inserts, one bare Ti face | - | carrier_flange; moving_flange | machine shop |  | 1 |  | USD | 150 | 600 | 150 | 600 | ASSUMPTION | one-off CNC |  |  | 2-4 weeks |  | results/revK/revK_pen_assembly.step (carrier_flange); results/improvement/mechanics/extended_reach_nib.step (moving_flange) | Ti-6Al-4V; 440C inserts | CNC turning, lapping of the faces | faces parallel <= 2 um; thickness +-0.005 mm | shop | S2 | N | N | a bare Ti face sees 2.6 GPa Hertz stress (CALC): EXP-BB05 checks for marks
B2 | 22 | purchased | Wave springs about 4 N at working height, several rates (preload steps 1-4 N) | class (Smalley class) | - | spring distributor |  | 6 |  | USD | 4 | 15 | 24 | 90 | ASSUMPTION | not priced here |  |  | 1-3 weeks |  |  |  |  |  | hobbyist | S2 | N | N
B2 | 23 | instrument | Low-capacity load cell 10 g (0.1 N) for guide drag (+-0.1 % RO) | FUTEK | LSB200 FSH03867 | futek.com (quote) |  | 1 |  | USD | 450 | 900 | 450 | 900 | ASSUMPTION | price not displayed (as B1 line 4) |  |  | 1-4 weeks (ASSUMPTION) | AMF-225 |  |  |  |  | supplier | S2 | N | N | the K3D40 plate cannot judge a 5 mN line (TUR < 1, bench_calcs.json)
B2 | 24 | instrument | Tilt measurement: laser lever (diode laser + position-sensitive detector); an autocollimator costs 3,000-8,000 | class | - | optics retailer |  | 1 |  | USD | 300 | 900 | 300 | 900 | ASSUMPTION | not priced here |  |  | 1-3 weeks |  |  |  |  |  | hobbyist | S2 | N | N
B2 | 25 | fabricated | Drop rig: 1 m guide tube and a dummy pen carrying the guide | - | PROPOSED DESIGN | in-house |  | 1 |  | USD | 30 | 100 | 30 | 100 | ASSUMPTION | tube and filament |  |  | 1 week |  |  | PETG body; acrylic tube | FDM | +-0.3 mm | hobbyist | S2 | N | N
B2 | 26 | service | Race surface profilometry before and after drops | - | - | metrology lab |  | 2 |  | USD | 100 | 400 | 200 | 800 | ASSUMPTION | per session, not quoted |  |  | 1-2 weeks |  |  |  |  |  | supplier | S2 | N | N
B2 | 27 | purchased | 301 stainless foil, hard, 0.035 mm target (0.030/0.038 mm alternatives; measure each sheet) | Goodfellow | AISI 301 foil (code per thickness) | goodfellow.com | - | 1 | 252.0 | USD | 252.0 | 252.0 | 252 | 252 | MANUFACTURER | https://www.goodfellow.com/usa/aisi-301-stainless-steel-foil-group | 2026-09-30 | '$252.00' starting price; thickness band 0.01-0.05 mm listed in the tolerance table | not shown (ASSUMPTION 2 weeks) | AMF-312 |  |  |  |  | supplier | S2 | N | N
B2 | 28 | service | Precision photo-etching or UV-laser micromachining of the 4-beam anchor (beam width +-0.01 mm), artwork set from the measured foil | - | floating_anchor_coupon.step | precision etcher (quote) |  | 1 |  | USD | 300 | 1500 | 300 | 1500 | ASSUMPTION | first batch with tooling, not quoted |  |  | 2-4 weeks (ASSUMPTION) |  | results/improvement/mechanics/floating_anchor_coupon.step | 301 full-hard foil | photochemical etching or UV/femtosecond laser cutting | beam width +-0.01 mm; burr-free | supplier | S2 | N | N | Ponoko's service (+-0.13 mm, minimum feature 1 mm, AMF-313) cannot make 0.5 mm beams
B2 | 29 | service | Flexible interconnect for the anchor (polyimide flex, within the ~23 N/m axial allowance) | - | PROPOSED DESIGN | flex-PCB prototype service |  | 1 |  | USD | 50 | 300 | 50 | 300 | ASSUMPTION | not quoted |  |  | 1-3 weeks |  |  |  |  |  | supplier | S2 | N | N
B2 | 30 | instrument | Precision balance, >= 1 mg readability (force by weighing: anchor stiffness, wire preload) | class | - | lab supplier |  | 1 |  | USD | 200 | 2500 | 200 | 2500 | ASSUMPTION | not priced here |  |  | 1-2 weeks |  |  |  |  |  | hobbyist | S2 | N | Y
B2 | 31 | instrument | Micrometer head 1 um (or the XYZ stage) for the anchor hub displacement | class | - | any |  | 1 |  | USD | 80 | 400 | 80 | 400 | ASSUMPTION | not priced here |  |  | 1-2 weeks |  |  |  |  |  | hobbyist | S2 | N | N
B2 | 32 | fabricated | Anchor test frame: hub pusher, outer-ring clamp, flatness datum | - | PROPOSED DESIGN | in-house or shop |  | 1 |  | USD | 50 | 200 | 50 | 200 | ASSUMPTION | not quoted |  |  | 1-2 weeks |  |  | 6061 / PETG | CNC or FDM | +-0.02 mm on the clamp datum | shop | S2 | N | N
B2 | 33 | instrument | Second 3-axis force sensor +-2 N under the refill carrier (residual side load) | ME-Messsysteme | K3D40 +-2N | me-systeme.de (quote) |  | 1 |  | USD | 900 | 1900 | 900 | 1900 | ASSUMPTION | as B1 line 2 |  |  | 2-6 weeks (ASSUMPTION) | AMF-224 |  |  |  |  | supplier | S2 | N | N | the protocol names a 6-axis cell (ATI Nano17, price not seen, AMF-223; ASSUMPTION 5,000-9,000): the K3D40 gives forces, not the couple
B2 | 34 | fabricated | Counter-face bench parts: 6 mm hardened disc on a cross-strip flexure, constant-force strip spring, follower stop, rolling refill guide and carrier | - | PROPOSED DESIGN in docs/balanced_nib.md (no STEP yet) | machine shop |  | 1 |  | USD | 300 | 1000 | 300 | 1000 | ASSUMPTION | one-off |  |  | 2-4 weeks |  |  | 17-4PH / 440C; spring steel | CNC, wire EDM | +-0.01 mm | shop | S2 | N | N | open item: the part (c) fixture has no CAD

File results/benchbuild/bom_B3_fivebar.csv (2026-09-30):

build | line | kind | item | manufacturer | part_number | supplier | supplier_pn | qty | unit_price_seen | currency | unit_usd_low | unit_usd_high | line_usd_low | line_usd_high | price_label | price_source | seen | availability | lead_time | ledger | fabrication_source | material | process | tolerance_finish | who | stage | mvp | optional_if_lab_has_it | notes
B3 | 1 | purchased | Brushed coreless DC motor 22 mm, 12 V (two + one spare) | Faulhaber | 2224U012SR (DigiKey listing: manufacturer number '2224.11000') | DigiKey (marketplace) | 5293-2224.11000-ND | 3 | 122.6 | USD | 122.6 | 122.6 | 368 | 368 | MANUFACTURER | https://www.digikey.com/en/products/result?keywords=5293-2224.11000-ND | 2026-09-30 | 7 in stock; 'Will ship in approximately 5 days from Faulhaber'; USD 9 flat shipping | about 1 week | AMF-304 |  |  |  |  | hobbyist | S3 | N | N | found by searching 2224U012SR; confirm the catalogue code is the 2224 U 012 SR before ordering (RS 873-4795: 12 V, 6.7 mNm, 4390 rpm)
B3 | 2 | purchased | Output-shaft magnetic encoder, 14-bit, on adapter board (two + one spare) | ams OSRAM | AS5047P adapter board | DigiKey | 4991-AS5047PADAPTERBOARD-ND | 3 | 19.4 | USD | 19.4 | 19.4 | 58 | 58 | MANUFACTURER | https://www.digikey.com/en/products/result?keywords=AS5047P-TS_EK_AB | 2026-09-30 | 397 in stock | 1-5 days | AMF-307 |  |  |  |  | hobbyist | S3 | N | N | the AS5047P IC is listed as discontinued at DigiKey: buy the boards now; FiveBar assumes 16-bit (1.99 um vs 7.98 um quantisation, bench_calcs.json)
B3 | 3 | purchased | Diametric encoder magnets 6 x 2.5 mm | class | - | magnet retailer |  | 4 |  | USD | 2 | 8 | 8 | 32 | ASSUMPTION | not priced here |  |  | 1 week |  |  |  |  |  | hobbyist | S3 | N | N
B3 | 4 | purchased | Motor driver with current sense (DRV8874 carrier), current loop run in the controller Teensy | Pololu | 4035 | pololu.com | 4035 | 3 | 11.94 | USD | 11.94 | 11.94 | 36 | 36 | MANUFACTURER | https://www.pololu.com/product/4035 | 2026-09-30 | 'Active and Preferred' | 1 week | AMF-305 |  |  |  |  | hobbyist | S3 | N | N | alternative: maxon ESCON Module 24/2 (466023), EUR 97.68 (1-4), NRND, current-controller mode (AMF-306)
B3 | 5 | purchased | Deep-groove bearings MR63-ZZ 3 x 6 x 2.5 mm (elbows, pen joint, output shafts) | class (Bearings Direct stock) | MR63-ZZ | Bearings Direct | MR63-ZZ | 12 | 4.38 | USD | 4.38 | 4.38 | 53 | 53 | MANUFACTURER | https://bearingsdirect.com/mr63-zz-mini-ball-bearing-3x6x2-5-shielded-l-630zz/ | 2026-09-30 | 684 available; usually ships in 24 hours | 1 week | AMF-316 |  |  |  |  | hobbyist | S3 | N | N | 10-24 units 5 % off; ABEC grade not stated
B3 | 6 | purchased | Ground shafts 3 mm h6 (dowel pins) and 2 mm set-screw hubs | class | - | any |  | 1 |  | USD | 15 | 40 | 15 | 40 | ASSUMPTION | not priced here |  |  | 1 week |  |  |  |  |  | hobbyist | S3 | N | N
B3 | 7 | consumable | Capstan cable (braided Dyneema 0.3-0.5 mm or 7x7 stainless 0.45 mm) and tensioners | class | - | any |  | 1 |  | USD | 15 | 50 | 15 | 50 | ASSUMPTION | not priced here |  |  | 1 week |  |  |  |  |  | hobbyist | S3 | N | N
B3 | 8 | purchased | Latching emergency stop and relay removing the motor supply | class | - | any |  | 1 |  | USD | 25 | 80 | 25 | 80 | ASSUMPTION | not priced here |  |  | 1 week |  |  |  |  |  | hobbyist | S3 | N | N | DEC-099 proposed
B3 | 9 | purchased | 12 V 60 W supply for the motors | Mean Well | GST60A12-P1J | DigiKey | product 7703712 | 1 | 19.4 | USD | 19.4 | 19.4 | 19 | 19 | MANUFACTURER | https://www.digikey.com/en/products/result?keywords=GST60A12-P1J | 2026-09-30 | in stock (Normally Stocking) | 1-5 days | AMF-308 |  |  |  |  | hobbyist | S3 | N | N
B3 | 10 | purchased | Controller board Teensy 4.1 (five-bar current and position loops; logs the DAQ sync pulse) | PJRC | Teensy 4.1 | SparkFun | DEV-16771 | 1 | 31.5 | USD | 31.5 | 31.5 | 32 | 32 | MANUFACTURER | https://www.sparkfun.com/teensy-4-1.html | 2026-09-30 | In stock | 1-5 days | AMF-220 |  |  |  |  | hobbyist | S3 | N | N
B3 | 11 | purchased | Pen lift for the dummy pen: micro servo (first build; a voice coil if the 0.5 s lift is too slow) | class | - | any |  | 1 |  | USD | 8 | 25 | 8 | 25 | ASSUMPTION | not priced here |  |  | 1 week |  |  |  |  |  | hobbyist | S3 | N | N
B3 | 12 | purchased | Hand-simulant springs 200 and 500 N/m on a linear guide | class | - | any |  | 1 |  | USD | 20 | 80 | 20 | 80 | ASSUMPTION | not priced here |  |  | 1 week |  |  |  |  |  | hobbyist | S3 | N | N
B3 | 13 | fabricated | Desk reaction base 170 x 165 x 5 mm (motor and bearing bores; base spacing 50.00 mm) | - | desk_reaction_base | machine shop |  | 1 |  | USD | 80 | 300 | 80 | 300 | ASSUMPTION | one-off |  |  | 1-3 weeks |  | results/improvement/mechanics/grounded_fivebar.step (desk_reaction_base) | 6061-T6 plate | waterjet + CNC finishing | bores +-0.02 mm; base spacing 50.00 +-0.02 mm | shop | S3 | N | N
B3 | 14 | fabricated | Output bearing supports (x2) | - | output_bearing_support_0/1 | machine shop |  | 1 |  | USD | 60 | 200 | 60 | 200 | ASSUMPTION | one-off |  |  | 1-3 weeks |  | results/improvement/mechanics/grounded_fivebar.step (output_bearing_support_0, _1) | 6061-T6 | lathe | bearing bores H7; coaxial 0.01 mm | shop | S3 | N | N
B3 | 15 | fabricated | Capstans: output R18 mm (x2) and motor R3 mm (x2), 6:1, helical cable groove | - | output_capstan_0/1, motor_capstan_0/1 | machine shop |  | 1 |  | USD | 80 | 300 | 80 | 300 | ASSUMPTION | one-off |  |  | 1-3 weeks |  | results/improvement/mechanics/grounded_fivebar.step (output_capstan_*, motor_capstan_*) | 6061-T6 (output); brass (motor, 2 mm bore) | CNC turning | groove pitch +-0.02 mm | shop | S3 | N | N | a printed first try is possible; cable routing and tensioner are unresolved in the CAD
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

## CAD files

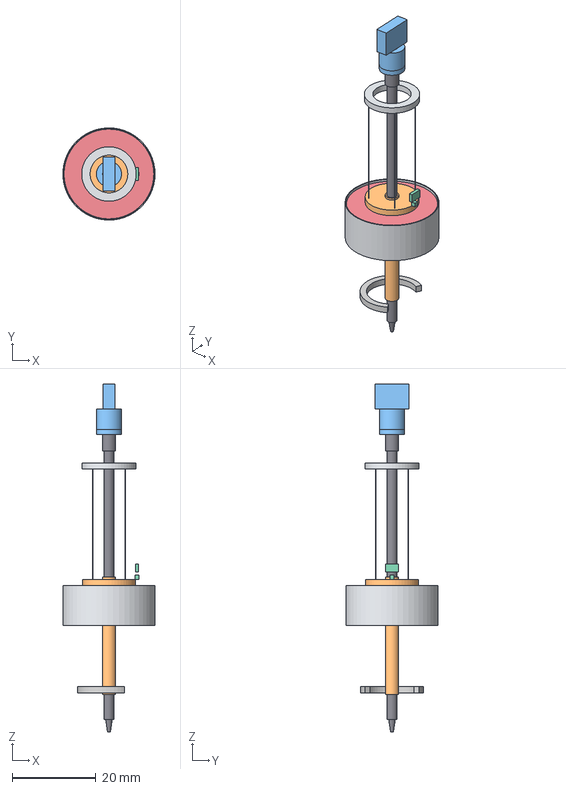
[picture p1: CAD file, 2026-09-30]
results/bnib/bnib_assembly.step
22.0 x 22.0 x 83.0 mm
ball
refill
bnib_refill_end
bnib_carrier
bnib_coils
bnib_carrier_flange
bnib_hall_magnet
bnib_back_plate
bnib_magnet_1
bnib_magnet_2
bnib_magnet_3
bnib_magnet_4
bnib_keeper
bnib_stator_housing
bnib_wire_1
bnib_wire_2
bnib_wire_3
bnib_wire_4
bnib_anchor_ring
bnib_hall
bnib_face
bnib_face_spring
bnib_face_positioners
bnib_skid_ring

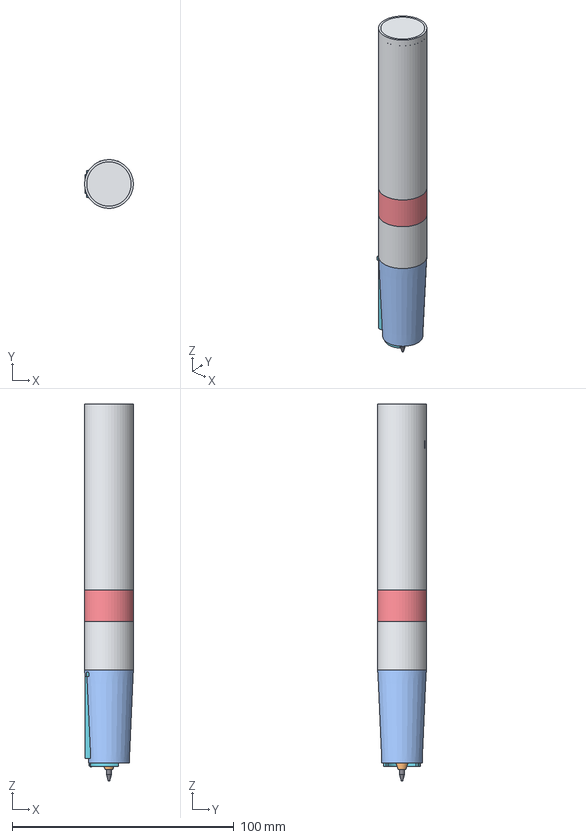
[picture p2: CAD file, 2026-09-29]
results/cad/heel_drive_assembly.step
22.0 x 22.0 x 170.0 mm
ball
refill
refill_spring
carrier
carrier_nozzle
arm
magnet_hub
magnet_x+
magnet_x-
magnet_y+
magnet_y-
hall_magnet
gimbal
back_ring
coil_x+
coil_x-
coil_y+
coil_y-
hall3d
pcb
imu
battery
lra
usb
rear_cap
rm_frame
rm_mass
rm_coils
drive_skid_ring
drive_wheel
drive_fork
drive_pod
drive_spring
drive_load_sensor
drive_steer_sensor
drive_shaft_drive
drive_shaft_steering
drive_keel
drive_paper_sensor
drive_transfer
drive_motor
steer_motor
drive_front_sleeve
drive_drivers

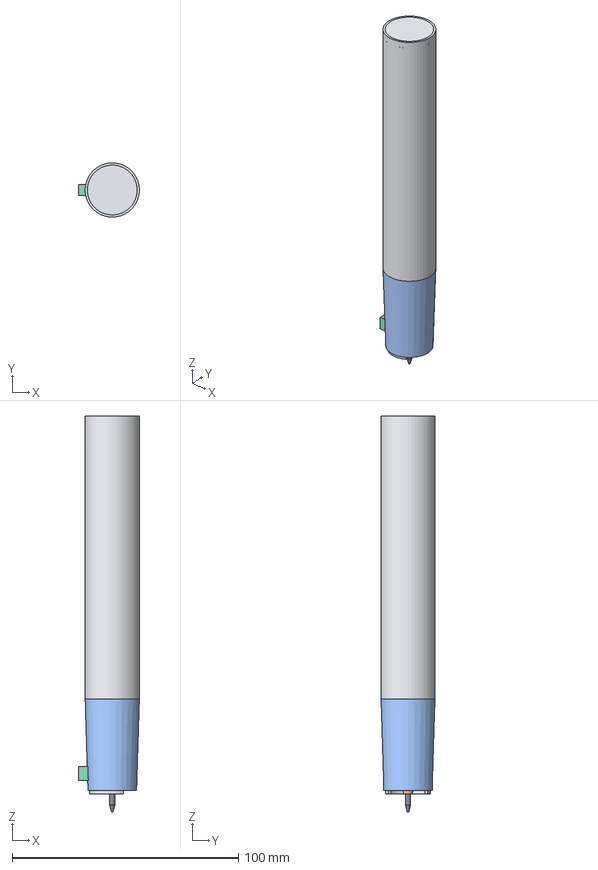
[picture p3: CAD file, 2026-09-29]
results/nose2/nose2_assembly.step
26.9 x 24.0 x 175.0 mm
ball
refill
refill_spring
refill_lift
carrier
carrier_nozzle
arm
magnet_cap
coil_plate
hall_magnet
hall3d
skid_ring
front_sleeve
optical
gimbal
pcb
imu
battery
lra
usb
rear_cap

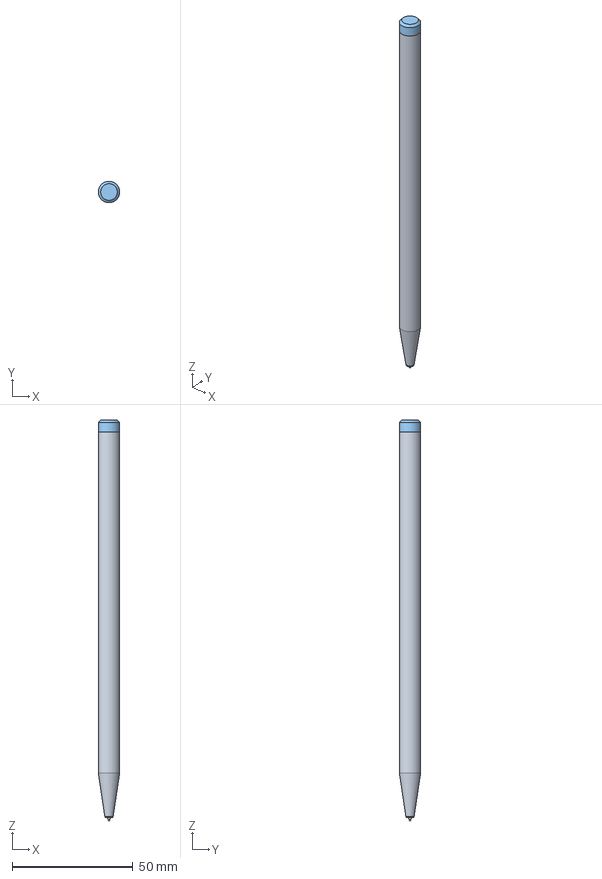
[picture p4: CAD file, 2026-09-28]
results/opt/cad/pencil_revPQ_P02_assembly.step
8.89 x 8.90 x 166.3 mm
barrel
skid_ring
rear_cap
clamp_block
bulkhead
battery
gimbal_flexure
pcb
pcb_components_envelope
hall_3d_nose
optical_sensor
snubber_1
snubber_2
snubber_3
snubber_4
bender_x_neg
bender_x_pos
bender_y_neg
bender_y_pos
leaf_x_neg
leaf_x_pos
leaf_y_neg
leaf_y_pos
refill_D1
collar
collar_liner
collar_magnet
gimbal_hub
rear_plug
axial_magnet
nib_spring

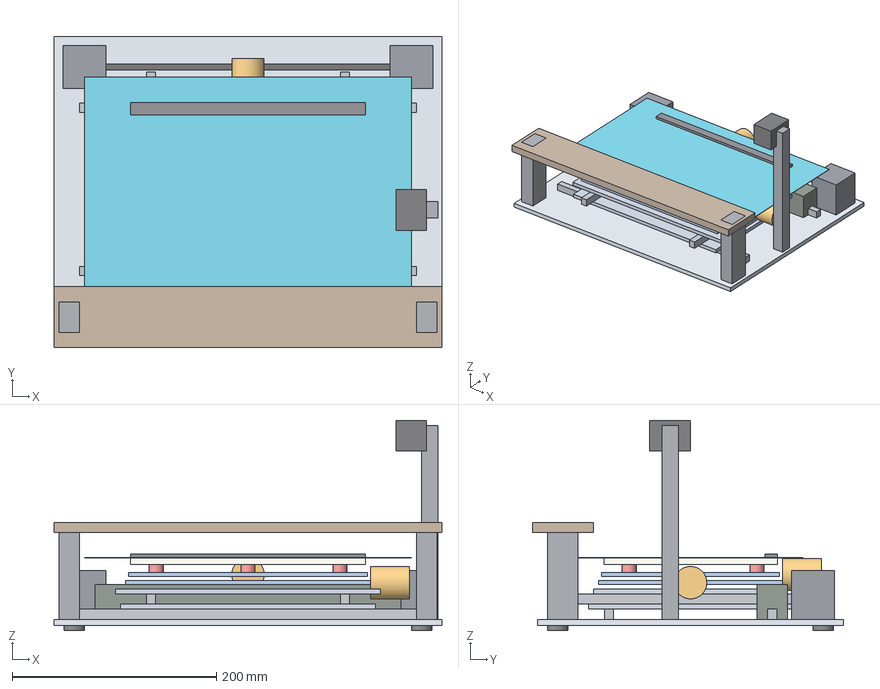
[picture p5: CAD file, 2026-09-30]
results/platen/platen_assembly.step
380.0 x 305.0 x 206.0 mm
base_plate
foot_-1_-1
foot_-1_1
foot_1_-1
foot_1_1
coarse_x_rail_-1
coarse_x_rail_1
coarse_x_carriage
coarse_y_rail_-1
coarse_y_rail_1
coarse_y_carriage
hbot_motor_-1
hbot_motor_1
hbot_belt_keepout
fine_x_frame
fine_y_carrier
vca_x
vca_y
load_cell_zdrop_0
load_cell_zdrop_1
load_cell_zdrop_2
paper_plate
paper_A5
clip_bar
plate_swept_envelope
palm_post_-1
palm_post_1
palm_rest_bridge
camera_post
camera
electronics_box

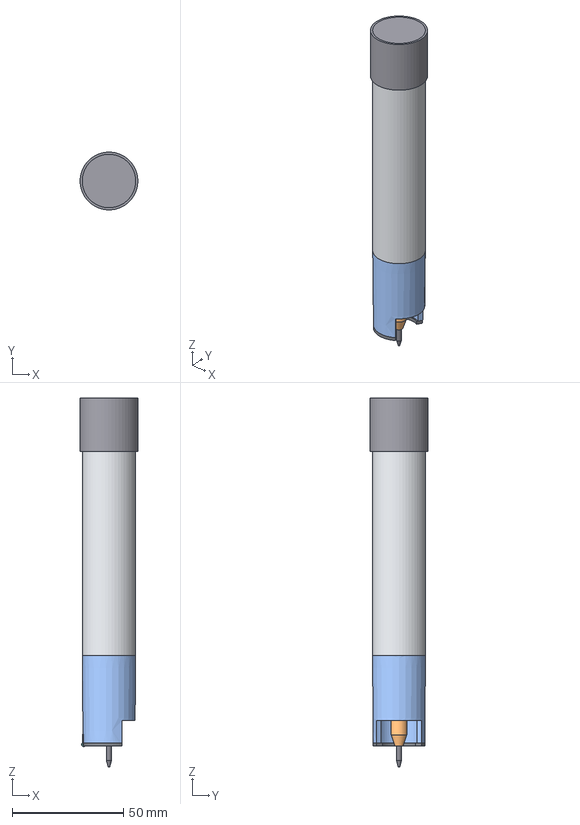
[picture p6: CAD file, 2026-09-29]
results/revJ/revJ_pen_assembly.step
26.0 x 26.0 x 165.7 mm
ball
refill
refill_holder
carrier_nozzle
carrier
front_pulley
pen_lift
slide_sensor
arm
rear_pulley
position_magnet
magnet_cap
coil_plate
gimbal
skid_ring
front_sleeve
main_board
imu
nose_hall
page_sensor
usb
battery
lra
drive_wheel
drive_fork
drive_pod
drive_spring
drive_load_sensor
drive_steer_sensor
drive_shaft_drive
drive_shaft_steering
drive_transfer
drive_motor
steer_motor
ec_shell
ec_end_wall
ec_board
ec_slug
ec_flexure_front
ec_flexure_rear
ec_magnet_x+
ec_magnet_x-
ec_magnet_y+
ec_magnet_y-
ec_coils

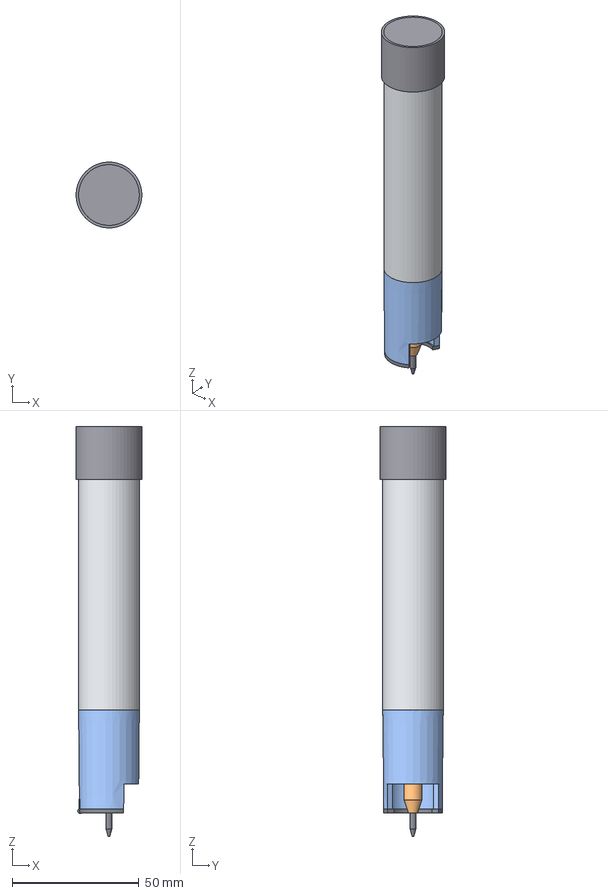
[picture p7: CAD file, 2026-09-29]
results/revJ1/revJ1_pen_assembly.step
26.0 x 26.0 x 161.8 mm
ball
refill
refill_holder
carrier_nozzle
carrier
front_pulley
pen_lift
slide_sensor
arm
rear_pulley
position_magnet
magnet_cap
coil_plate
gimbal
skid_ring
front_sleeve
main_board
imu
nose_hall
page_sensor
usb
battery
lra
drive_wheel
drive_fork
drive_pod
drive_spring
drive_load_sensor
drive_steer_sensor
drive_shaft_drive
drive_shaft_steering
drive_transfer
drive_motor
steer_motor
heat_spreader
ec_shell
ec_end_wall
ec_board
ec_slug
ec_flexure_front
ec_flexure_rear
ec_magnet_x+
ec_magnet_x-
ec_magnet_y+
ec_magnet_y-
ec_coils

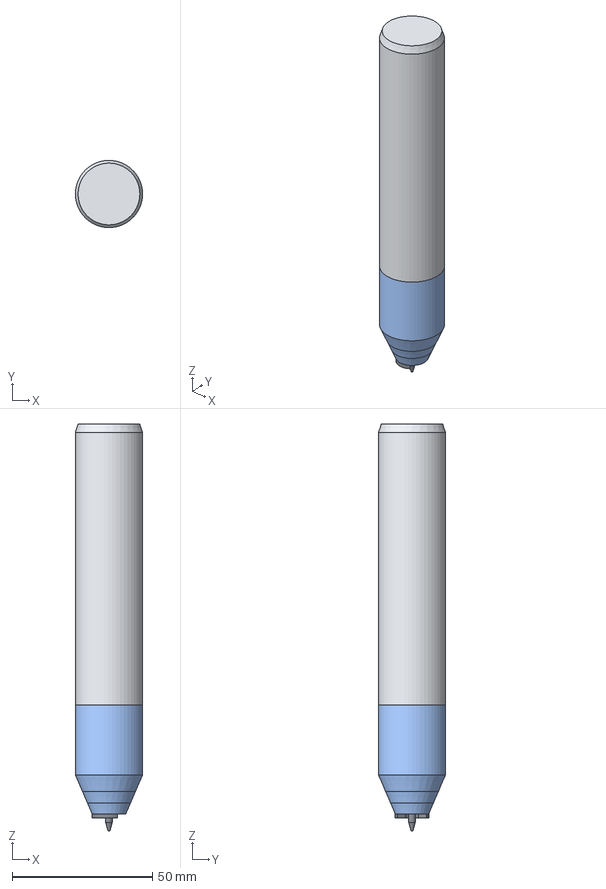
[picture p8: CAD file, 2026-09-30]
results/revK/revK_pen_assembly.step
24.0 x 24.0 x 145.1 mm
ball
refill
carrier
carrier_front_guide
carrier_rear_guide
coil_x
coil_y
carrier_flange
position_magnet
back_plate
pole_magnet_1
pole_magnet_2
pole_magnet_3
pole_magnet_4
keeper
front_race
front_balls
rear_balls
rear_race
lateral_stop
nose_hall
wire_1
wire_2
wire_3
wire_4
anchor_ring
skid_ring
front_cone_1
front_cone_2
front_cone_3
front_sleeve
page_optics
page_sensor
main_board
board_parts
imu
refill_holder
head_cage
head_carriage
head_shoe
head_face
head_float
head_tilt_motor
head_balance_spring
face_hall
head_roll_motor
head_follower_motor
head_flex
bulkhead
battery
lra
rear_cap
charging_pads

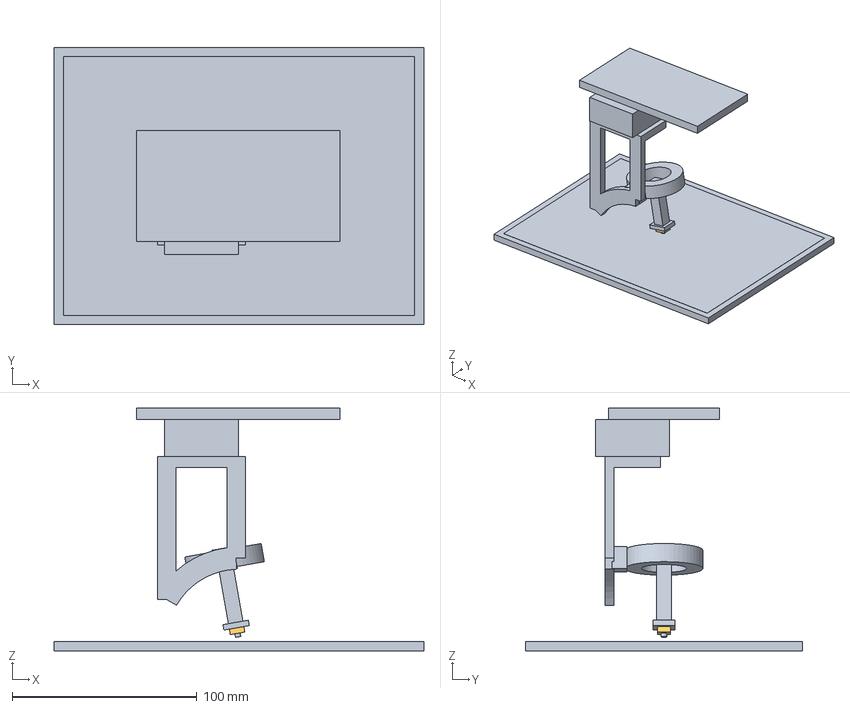
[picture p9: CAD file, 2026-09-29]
results/rig/cad/rig_pagesense_sled_assembly.step
200.0 x 150.0 x 131.1 mm
paper
glass_platen
sled_lens
sled_die
sled
roll_ring
arc_carriage
tilt_arc
z_micrometre_stage
head_plate

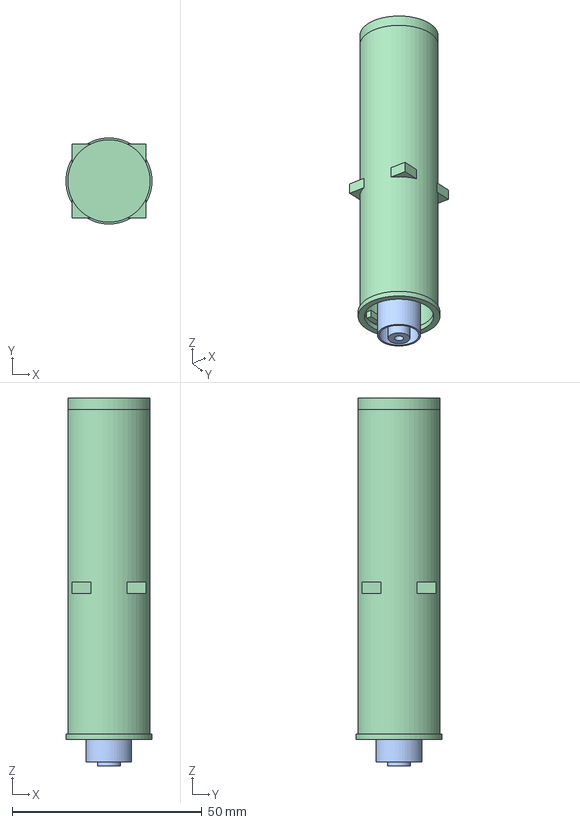
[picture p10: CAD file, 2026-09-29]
results/wholepen/cad/wholepen_collar.step
22.7 x 22.7 x 97.0 mm
collar_sleeve
collar_skid_ring
collar_pivot
collar_coil_plate
collar_end_wall
collar_load_cell
inner_barrel
fine_nib
inner_board
inner_cell
inner_magnets

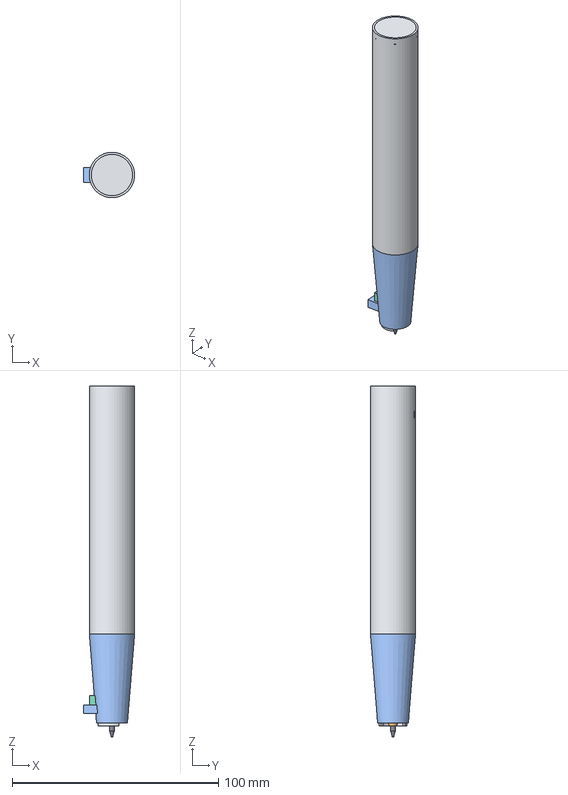
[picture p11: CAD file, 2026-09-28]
results/cad/revH_pen_assembly.step
24.9 x 22.0 x 170.0 mm
ball
refill
refill_spring
carrier
carrier_nozzle
arm
magnet_hub
magnet_x+
magnet_x-
magnet_y+
magnet_y-
hall_magnet
skid_ring
front_sleeve
gimbal
back_ring
coil_x+
coil_x-
coil_y+
coil_y-
hall3d
pcb
imu
battery
lra
usb
rear_cap
optical
board_magnet
board_keel

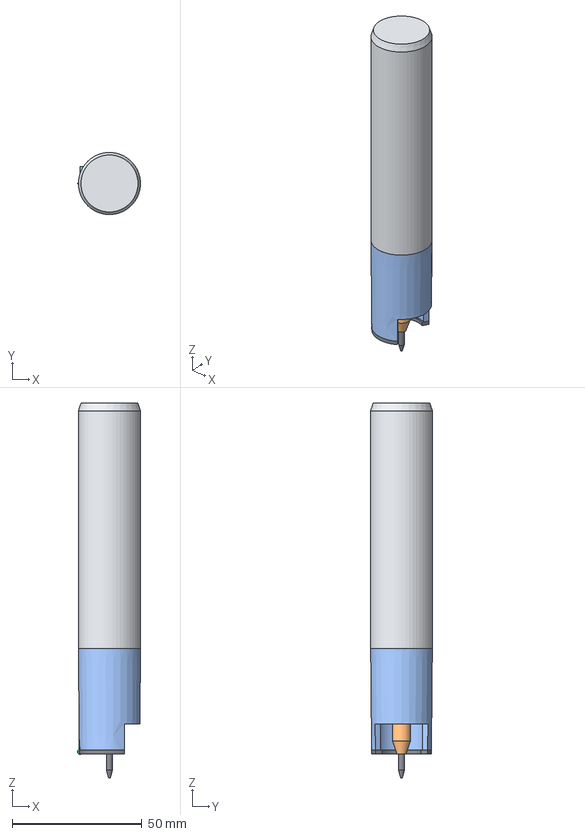
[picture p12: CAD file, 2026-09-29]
results/revJ/revJ_pen_assembly_no_endcap.step
24.4 x 24.0 x 144.7 mm
ball
refill
refill_holder
carrier_nozzle
carrier
front_pulley
pen_lift
slide_sensor
arm
rear_pulley
position_magnet
magnet_cap
coil_plate
gimbal
skid_ring
front_sleeve
rear_cap
main_board
imu
nose_hall
page_sensor
usb
battery
lra
drive_wheel
drive_fork
drive_pod
drive_spring
drive_load_sensor
drive_steer_sensor
drive_shaft_drive
drive_shaft_steering
drive_transfer
drive_motor
steer_motor

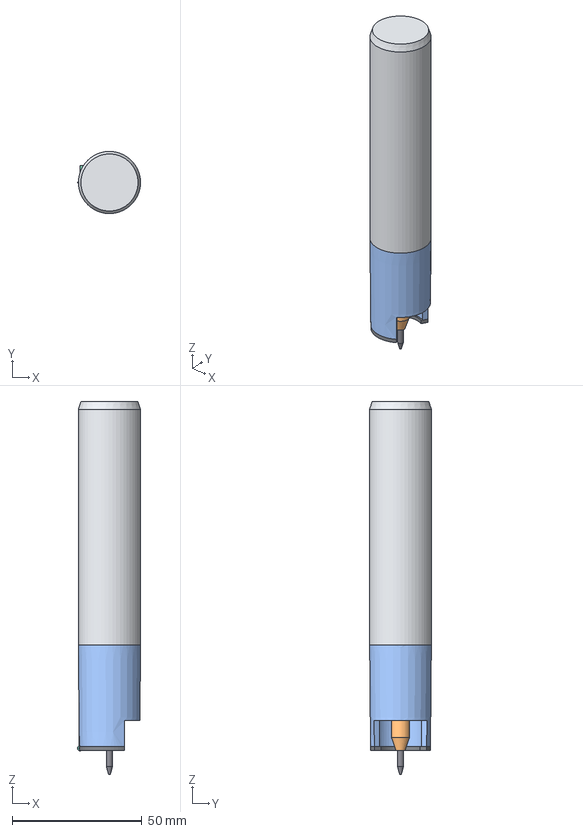
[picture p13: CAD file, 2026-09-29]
results/revJ1/revJ1_pen_assembly_no_endcap.step
24.4 x 24.0 x 143.9 mm
ball
refill
refill_holder
carrier_nozzle
carrier
front_pulley
pen_lift
slide_sensor
arm
rear_pulley
position_magnet
magnet_cap
coil_plate
gimbal
skid_ring
front_sleeve
rear_cap
main_board
imu
nose_hall
page_sensor
usb
battery
lra
drive_wheel
drive_fork
drive_pod
drive_spring
drive_load_sensor
drive_steer_sensor
drive_shaft_drive
drive_shaft_steering
drive_transfer
drive_motor
steer_motor
heat_spreader

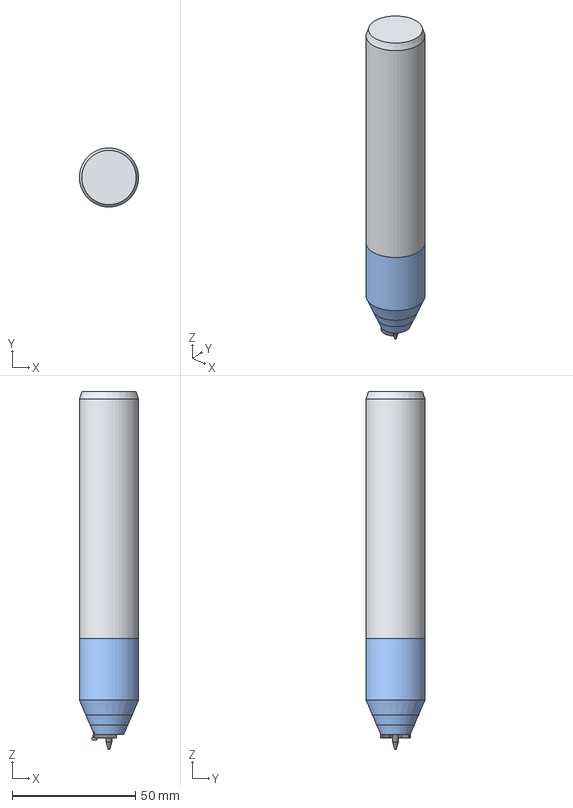
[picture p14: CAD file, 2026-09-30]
results/revK/revK_pen_assembly_heel.step
24.0 x 24.0 x 145.1 mm
ball
refill
carrier
carrier_front_guide
carrier_rear_guide
coil_x
coil_y
carrier_flange
position_magnet
back_plate
pole_magnet_1
pole_magnet_2
pole_magnet_3
pole_magnet_4
keeper
front_race
front_balls
rear_balls
rear_race
lateral_stop
nose_hall
wire_1
wire_2
wire_3
wire_4
anchor_ring
skid_ring
front_cone_1
front_cone_2
front_cone_3
front_sleeve
page_optics
page_sensor
main_board
board_parts
imu
refill_holder
head_cage
head_carriage
head_shoe
head_face
head_float
head_tilt_motor
head_balance_spring
face_hall
head_roll_motor
head_follower_motor
head_flex
bulkhead
battery
lra
rear_cap
charging_pads
drive_wheel
drive_fork
drive_pod
drive_inner_shaft_drive
drive_inner_shaft_steering
drive_front_transfer
drive_shaft_drive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

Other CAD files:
results/rig/cad/rig_grip_assembly.step
results/cad/revH_pen_addon_assembly.step
results/rig/cad/rig_recpen_assembly.step
results/cad/guidance_board_assembly.step
results/cad/bench_rig_assembly.step
results/cad/part_barrel.step
results/cad/part_carrier.step
results/cad/part_coil_paddle.step
results/cad/part_magnet_front.step
results/cad/part_magnet_rear.step
results/cad/part_rear_plug.step
results/cad/part_refill_D1.step
results/cad/part_sensing_magnet.step
results/cad/part_stop_ring.step
results/cad/pen_revA1_assembly.step
results/cad/pen_revA_assembly.step
results/cad/pencil_revPL_assembly.step
results/cad/pencil_revPQ_assembly.step
results/endcap/endcap_cmg.step
results/endcap/endcap_lrm.step
results/improvement/mechanics/extended_reach_nib.step
results/improvement/mechanics/floating_anchor_coupon.step
results/improvement/mechanics/grounded_fivebar.step
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

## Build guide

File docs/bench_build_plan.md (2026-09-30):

# The first bench build plan (study H)

**Status: PROPOSED PLAN, 30 September 2026. Nothing has been bought, built or measured.** This plan turns study M's rigs, the gates of `validation/prototype_stages.md`, Rev K's layout and the independent engineering pass's proposed nib and five-bar into a build that a small team can order and run.

**Labels.** Every number carries one of these:
- **MANUFACTURER**: a manufacturer's or distributor's statement, with its part number, source page, date seen and ledger id. Prices were seen on 2026-09-30. Rows AMF-300…322 and OPT-100…101 are in `results/benchbuild/evidence_rows.csv`; earlier rows are in `docs/evidence.csv`.
- **LITERATURE**: a published source, with its ledger id.
- **CALCULATION**: a calculation, with its file.
- **ASSUMPTION**: an input nobody has measured, or a labelled price range where no price was visible. The reason is given.
- **SIM**: synthetic data run through the analysis code. It checks the software, not a device.

---

## Plain-language summary

**What to buy and build first.** Start with the minimum viable first build: the data box DAQ-1 and the contact-and-ink rig R9.
- DAQ-1 is a Teensy 4.1 board and TI's 24-bit ADS131M08 evaluation board. Every instrument is time-stamped on its one clock.
- R9 is built on a Prusa CORE One+ printer kit, which moves the pen head over a fixed bed.
- Under the paper sits a ±2 N three-axis force sensor. Behind the refill sits a 1 N load cell, and dead weights set the refill force.
- The rest is refills, six papers, a calibration weight set and a 4800 dpi scanner.

Order every long-lead item for the later builds in the same week: the force sensors, the coil winding, the lapped races, the etched anchor, the beryllium-copper wire and the page-sensor boards.

**What it costs.**
- **First build: about USD 4,350–7,750.** Parts whose price was visible enter at that price (MANUFACTURER). The force sensors and machined parts enter as ASSUMPTION ranges, because their makers show prices only on request. Add about USD 1,700–2,400 if the lab has no oscilloscope, 4-wire meter, bench supply, soldering station or hand tools.
- **All five builds: about USD 14,000–35,400.** This covers the DAQ, R9 and its upgrades, the coupons, the five-bar and the page-sensing rig. Add USD 2,800–7,500 of instruments if the lab has none. The spread is wide because most coupon hardware is custom and has no visible price.
- Shipping, tax, duty and labour are excluded.

**How long it takes.**
- **Weeks 0–2:** ordering, pre-registration and the DAQ bring-up.
- **Weeks 1–4:** the first G1 answers, provided the force sensors arrive within about three weeks. Their lead time is not published: ASSUMPTION 2–6 weeks, so order them on day 1.
- **Weeks 3–8:** the G2 coupons. Coil winding, lapped races and precision etching take about 3–6 weeks (ASSUMPTION). Each batch of wire-fatigue coupons then runs for 3–8 days.
- **Weeks 6–12:** the five-bar and page sensing.
- **Decision meetings:** at week 8 (G2) and week 12.

**What it will decide.**
1. **G1: how hard the refill must press to write without gaps on each paper, and what the paper pushes back.** This number sets the refill spring (DEC-050 is revisited above 0.3 N). With the friction map, it gives the side load the nib must carry. G1 also lists EXP-J17: only its counter-face part (c) runs in this build, because parts (a) and (b) need a built nose or nib.
2. **G2: whether Rev K's nib can be built, and which fine-stage candidate goes forward.**
   - The "Build Rev K's nib" gate of `validation/prototype_stages.md` §0 has three conditions:
     - the force constant is at least 0.7 × the model on Rev K's coil;
     - the beryllium-copper leads survive 43.2 M cycles;
     - the ball guide rolls with no more than 5 mN of friction.
   - DEC-072's choice between the 1.5 mm and the 1.059 mm stage waits for the measured load.
   - By the pass's own duty screen, the 1.5 mm candidate reaches the assumed 0.15 W copper allocation at about 34 mN of residual load (CALCULATION). Gravity on the moving nib alone is about 29.5 mN at 35° (CALCULATION).
   - Adding the other calculated loads gives about 49–51 mN at 35°: the face's residual of 11–13 mN at the 95th percentile and the guide drag of 8 mN (CALCULATION, a conservative sum of magnitudes). Unless the measured loads are lower, the 1.059 mm stage goes forward.
3. **The five-bar: whether a desk-grounded linkage writes accepted letters on real paper, and what happens when a hand resists it** (DEC-071).
4. **R10: whether a small optical sensor keeps its place on real paper, including through lifts.** This is the sensing build gate, and it chooses the die for Rev K.

**What changed while planning this.**
- **Supply risks.** The current amplifier the rigs were drawn around, TI's OPA548T, is back-ordered: none in stock at DigiKey, with 50 expected on 30 November 2026 (MANUFACTURER, AMF-301). A cheaper substitute (OPA564) and a PWM driver are listed. The page-sensor boards are out of stock or on pre-order (OPT-100, OPT-90).
- **The fatigue drive frequency.** bench_protocols.md runs EXP-B25's fatigue step at about 200 Hz (about 60 h), and EXP-K21 cycles its wires the same way. At 200 Hz the wires' own resonance adds stress the pen never sees (CALCULATION):
  - Rev K's 26.8 mm wires have first modes of about 487–763 Hz, and their clamp stress rises 12–33 %;
  - the reach candidate's 34 mm wires have first modes of about 336–373 Hz, and their clamp stress rises 66–90 %.
  - The plan drives each coupon at no more than 0.2 × its measured first mode (DEC-098 proposed).
- **The ball-guide preload.** The pass's 4 N preload is calculated to give about 8 mN of rolling drag, above EXP-K20's 5 mN line. The plan measures drag and tilt against preload (EXP-BB05).
- **The five-bar force cap.** A motor current limit cannot enforce the five-bar's 0.4 N cap. At rated current the linkage can push about 1.06 N at its worst pose (CALCULATION). A breakaway pen coupling is therefore part of the build (DEC-099 proposed).
- **Beryllium copper.** The alloy's safety data sheet names heat treating, pickling, abrasive cutting, welding and grinding as exposure routes (AMF-319). The wire is bought already hardened, cut with shears and soldered under local exhaust (DEC-097 proposed).

---

## 1. Scope and where things are

This plan covers five builds.

| Build | What it is | Gate (`prototype_stages.md`) | Main experiments |
|---|---|---|---|
| **B0 DAQ-1** | Teensy 4.1 + ADS131M08EVM + thermocouple amplifiers + current drive; one clock (`docs/measurement_rig.md` §1) | all (order 0) | EXP-BB01 (proposed) |
| **B1 R9** | Contact and ink rig on a CoreXY printer frame (`docs/measurement_rig.md` §2) | **G1** | EXP-T01, T02, BB02, BB09; hosts EXP-J17 (c) |
| **B2 G2 coupons** | Force-constant coupons (Rev K's coil, EXP-K22 in EXP-T07; the reach candidate's winding); C17200 wire coupons with a fatigue shuttle (EXP-K21, BB04); ball-guide coupons (EXP-K20, BB05); the floating anchor (EXP-BB03); the counter-face bench (EXP-J17 (c)) | **G2**; "Build Rev K's nib" | as listed |
| **B3 five-bar** | The pass's grounded demonstrator (`mechanics/cad/grounded_stage.py`) with Faulhaber 2224 motors | none yet | EXP-BB06, BB07 (proposed) |
| **B4 R10** | Page-sensor rig on R9's frame (`docs/measurement_rig.md` §3) | sensing build gate | EXP-T04, T05, BB08 |

Not in this first build:
- R11: the tablet protocol needs no build, and the recording pen waits for ethics approval.
- R13 and R14, which need a working nib.
- Rev K's counter-face head with its three SQL-RV-1.8 motors (EXP-K23). These are sold only to volume customers (AMF-15).
- Hall interference (EXP-T09), which needs a TMAG5170 board.

**Files** (all under `results/benchbuild/`):

| Purpose | Files |
|---|---|
| Bills of materials | `bom_B0_daq1.csv`, `bom_B1_r9_g1.csv`, `bom_B2_g2_coupons.csv`, `bom_B3_fivebar.csv`, `bom_B4_r10.csv`: every line with part number, supplier, price and label, source, date, stock, lead time, ledger id, STEP source, material, process, tolerance, who can make it, stage |
| Cost and schedule | `cost_schedule.csv`, `cost_totals.json` |
| Test-to-decision map | `test_decision_map.csv` |
| Proposed rows | `proposed_experiments.csv`, `proposed_criteria.csv` (the columns of `validation/acceptance_criteria.csv`), `proposed_decisions.csv` |
| Evidence | `evidence_rows.csv` (25 rows, 23 columns, CRLF) |
| First session | `first_measurement_checklist.md`, `templates/` (20 CSV data templates, a record and a verdict template, the lab-notebook page) |
| Checks and calculations | `pipeline_check.json`, `bench_calcs.json`, and the scripts in `tools/` that make every table (§15) |

**Other studies running now.**
- **Study N** (nibopt/) may change the fine-stage geometry. The coupon fixtures below take either candidate: the coil packs, races and anchor are drawn per candidate, and the magnets are stock stand-ins. Freeze the coil and race drawings when study N reports.
- **Study P** (platen/) studies a moving-paper platen, the alternative to the five-bar (DEC-071).
- **Study X** (rebaseline/) re-runs simulations with causal sensing (DEC-070). The contact-timing experiment EXP-BB09 feeds it.

## 2. The builds at a glance

The cost columns are sums of the BOM line ranges, taken from `cost_totals.json`. Line totals are rounded to whole dollars, so every total is an exact sum of its lines.

| Build | Core cost, USD | Instruments and tools if the lab has none, USD | Share of core (low end) priced from a seen page | Longest lead item | Who |
|---|---|---|---|---|---|
| B0 DAQ-1 | 859–1,179 | 1,716–2,416 | 78 % | OPA548T back-order to 30-Nov-2026 (AMF-301); not needed for the first build | small team |
| B1 R9 | 5,686–11,746 (the first build is 3,536–6,596 of it; §9.1) | — | 28 % | K3D40 and LSB200 (ASSUMPTION 2–6 weeks, quote) | small team + machine shop |
| B2 G2 coupons | 5,808–17,936 | 1,040–5,040 | 14 % | coil winding, lapped 440C races (ASSUMPTION 3–6 weeks) | machine shop + suppliers |
| B3 five-bar | 987–2,103 | reuses B1/B4 instruments | 57 % | CNC parts (ASSUMPTION 1–3 weeks); motors about 1 week (AMF-304) | machine shop + small team |
| B4 R10 | 628–2,475 | reuses B1 | 10 % | page-sensor boards (out of stock or pre-order, OPT-100, OPT-90) | small team |
| **All five** | **13,968–35,439** | **2,756–7,456** | | | |

---

## 3. B0: DAQ-1, the shared data box

**Purpose.** Every rig reads its instruments through DAQ-1. Each sample is stamped with the Teensy's 600 MHz cycle counter in one interrupt. A device with its own clock records the coded sync pulse and is mapped onto DAQ-1's clock (`docs/measurement_rig.md` §1.3; `rig/sync.py`).

### 3.1 Purchased parts

| Part | Manufacturer part number | Supplier (supplier part number) | Unit price, date seen, stock (label, ledger) | Qty |
|---|---|---|---|---|
| Microcontroller board | PJRC Teensy 4.1 | SparkFun (DEV-16771) | USD 31.50, 2026-09-30, in stock (MANUFACTURER, AMF-220) | 2 (+1 in B3) |
| 24-bit 8-channel ADC evaluation module | TI ADS131M08EVM | DigiKey (296-ADS131M08EVM-ND) | USD 328.11, 2 in stock; TI's page says in stock, price after login (MANUFACTURER, AMF-300) | 1 |
| Thermocouple amplifier | Adafruit 3263 (MAX31856) | Adafruit | USD 17.50, in stock (MANUFACTURER, AMF-234) | 4 |
| Type-T thermocouple, 0.08 mm class | class | instrument distributor | USD 15–40 each (ASSUMPTION: omega.com returned HTTP 403) | 8 |
| Current shunt 0.1 Ω ±0.1 %, 4-terminal foil | VPG Y14870R10000B9R | DigiKey (804-1045-1-ND) | USD 13.05; 0 in stock, 1,000 expected 12-Oct-2026 (MANUFACTURER, AMF-303) | 4 |
| Power op-amp for current drive | TI OPA548T | DigiKey | USD 21.55; 0 in stock, 50 expected 30-Nov-2026; TI store out of stock (MANUFACTURER, AMF-301) | 2 |
| 12 V 60 W supply | Mean Well GST60A12-P1J | DigiKey | USD 19.40 (MANUFACTURER, AMF-308) | 1 |
| Wiring, connectors, 12-core shielded cable, RC filters | class | any | USD 60–150 (ASSUMPTION) | 1 lot |

**The OPA548 problem.** The first build does not need it, because dead weights set the refill force. For R9's voice coil (under 0.5 A) and the coupon coils, there are two substitutes:
- OPA564AIDWP, a 1.5 A linear amplifier: DigiKey USD 9.51, stock not shown (AMF-301).
- A Pololu DRV8874 carrier driven at 40 kHz or more, with an output LC filter: USD 11.94 (AMF-305).

OPA549T is back-ordered to 2 December 2027 (AMF-301).

### 3.2 Fabricated parts, instruments and tools

- **Enclosure and connector panel.** PETG print or laser-cut acrylic, ±0.3 mm (hobbyist). There is no CAD: make it to fit the boards.
- **Instruments, if the lab has none:**
  - oscilloscope Rigol DHO804, USD 459.00, 40 in stock (MANUFACTURER, AMF-321);
  - 6.5-digit DMM with 4-wire ohms, Siglent SDM3065X, USD 857.00 (MANUFACTURER, AMF-322);
  - dual linear bench supply, USD 150–450 (ASSUMPTION).
- **Tools:**
  - temperature-controlled soldering station, USD 100–250 (ASSUMPTION);
  - bench fume absorber Hakko FA400-04, USD 93.79 (MANUFACTURER, AMF-317);
  - calipers, a 1 µm micrometer, tweezers, flush cutters and an ESD mat, USD 150–400 (ASSUMPTION).

### 3.3 Assembly

The steps follow `docs/measurement_rig.md` §1.2–§1.3 and the rig BOM's notes.
1. On the ADS131M08EVM, power AVDD through JP12/TP2 and DVDD through TP1 with R67 removed (TI SBAU334A §4; AMF-222). Wire the J10 header to the Teensy:
   - SPI0: pins 10 CS, 11 MOSI, 12 MISO and 13 SCK;
   - DRDY on pin 9, SYNC/RESET on pin 6.
2. Wire the remaining signals:
   - encoders to the QuadEncoder pins 2/3, 4/7, 8/30 and 31/33;
   - camera trigger 24, strobe 25, sync out 28, DUT sync in 29, marker in 32;
   - PWM pins 22 and 23 through RC filters to the current amplifiers;
   - the MAX31856 boards on chip selects 0, 1, 14 and 15;
   - the page sensor on SPI1 (26, 27, 39; chip select 36; motion line 34).
3. Feed the bridge excitation from the EVM's 3.3 V through 10 Ω and 10 µF, and read it ratiometrically on a spare channel.
4. Build `rig/firmware/rig_daq/rig_daq.ino` with Arduino IDE ≥ 2.3.10, Teensyduino 1.62 and QuadEncoder (AMF-237, AMF-238). The firmware has only been checked against stubs on a PC; this is its first compile for the board (§13).
5. Bring it up as EXP-BB01 (§14; checklist B). Nothing else is recorded until EXP-BB01 passes.

### 3.4 Safety

- The build is low-voltage.
- The OPA548 or OPA564 needs a heat sink and its current limit set below the coil's rating.
- Handle the boards on an ESD mat.
- No person is connected to this equipment: the first build is bench-only.

---

## 4. B1: R9, the contact and ink rig (G1)

**Purpose (`docs/measurement_rig.md` §2).** R9 measures two forces separately:
- the axial force the refill spring applies, F_c, from an in-line cell behind a leaf-guided refill;
- the force the ball applies to the paper, N plus friction, from a three-axis plate under the paper.

It then maps friction against speed, tilt and direction, and finds the lowest force that writes without gaps. The same frame later carries EXP-J17 (c) and R10.

### 4.1 Purchased parts and instruments

| Part | Manufacturer part number | Supplier | Unit price, date, stock (label, ledger) | Qty | First build? |
|---|---|---|---|---|---|
| CoreXY printer kit (motion frame) | Prusa CORE One+ (Gen 2) kit | prusa3d.com | USD 925; "In stock. Preparation time: 1–3 business days"; assembled USD 1,202.78 (MANUFACTURER, AMF-231, re-seen 2026-09-30) | 1 | yes |
| 3-axis force sensor ±2 N | ME-Messsysteme K3D40 ±2N | me-systeme.de | USD 900–1,900 (ASSUMPTION: price behind a login; AMF-224 has the specifications) | 1 | yes |
| 3-axis force sensor ±10 N | ME-Messsysteme K3D40 ±10N | me-systeme.de | USD 900–1,900 (ASSUMPTION) | 1 | no (N above the ±2 N plate's range; reused by B2 and B3) |
| In-line axial cell 100 g (1 N), 2 mV/V | FUTEK LSB200 FSH03870 | futek.com | USD 450–900 (ASSUMPTION: the store page shows $0.00; AMF-225 has the specifications) | 1 | yes |
| In-line axial cell 250 g (2.5 N) | FUTEK LSB200 FSH03871 | futek.com | USD 450–900 (ASSUMPTION, as above; AMF-225) | 1 | no (N up to 2 N at every tilt; G2-format refills) |
| Voice coil for F_c ramps | Moticont LVCM-013-013-03 | moticont.com | USD 150–350 (ASSUMPTION: no price on the page; AMF-02) | 1 | no (dead weights first) |
| Linear encoder with MS scale | RLS LM13, 13B | RLS distributor | USD 250–700 per axis (ASSUMPTION; OPT-89) | 2 | no (move timing first) |
| Slide Hall sensor | TI DRV5055A4QDBZR | DigiKey (296-50468-1-ND) | USD 0.87, 3,538 in stock (MANUFACTURER, AMF-302) | 4 | yes |
| Calibration weights OIML M1, 1 g–500 g | Mettler Toledo 30402728 | Scales Galore | USD 535.50, "Available to Ship" (MANUFACTURER, AMF-315) | 1 | yes |
| Scanner, 4800 dpi optical | Epson Perfection V39 II (B11B268201) | epson.com | USD 129.99 (MANUFACTURER, AMF-314) | 1 | yes |
| Refills: S 635 M ×20, easyFLOW 9000 ×10, P 8126 ×10, FL 6040 F ×10; a second D1 oil brand ×10 and a gel D1 ×10 | Schmidt Technology; class | stationery | USD 70–360 in all (ASSUMPTION; CON-100) | 1 lot | yes |
| Papers: copy 80 g/m², recycled, school ruled, coated, tracing, card | class | stationery | USD 60–150 (ASSUMPTION) | 1 pack each | yes |
| Jewel-bearing pulley and thread; inclinometer (0.1°); 0.05 mm spring-steel shim; USAF-1951 target; underlays and CFRP sheet; fasteners | class | any | USD 20–80; 30–120; 20–60; 50–200; 30–100; 30–80 (ASSUMPTION) | 1 each | yes |

**The scanner.** The V39 II is enough to find gaps in EXP-T02. R3's 5 µm (k = 2) ink-path metrology for G3 needs the Epson V850 Pro, USD 1,999 (MANUFACTURER, AMF-236), or a microscope. That purchase waits until G3.

### 4.2 Fabricated parts

All are taken from `results/rig/cad/rig_contact_assembly.step`, made by `mechanics/cad/rig_contact.py`.

| Part (solid name) | Material | Process | Tolerance and finish | Who | Cost (ASSUMPTION) |
|---|---|---|---|---|---|
| Tilt arc R 70 mm with holes at 35/50/65/75° (`arc_frame`) and its carriage (`arc_carriage`), first-build version | PETG or PA-CF | FDM 3-D print | ±0.2 mm; tilt set and read under load with the inclinometer | hobbyist | USD 10–40 |
| The same, standard version | 6061-T6 | CNC milling | hole pattern and radius ±0.05 mm; bead blast | machine shop | USD 150–600 |
| Cartridge frame with leaf clamps (`cartridge_frame`), refill holder and collet for D1 2.35 mm or G2 6 mm (`holder`), Hall bracket (`hall_bracket`) | 6061-T6; brass collet; printed bracket | CNC, lathe; FDM | ±0.02 mm on the leaf clamp faces; holder bore 2.4 H7 | machine shop | USD 150–500 |
| Guide leaves 0.05 × 8 × 25 mm ×2 (`guide_leaves`) | spring-steel shim | shear against a template, or photo-etch; deburr | ±0.05 mm, flat, no kinks | hobbyist | USD 0–25 |
| Bed adapter 120 × 100 × 6 mm (`bed_adapter`) and a head plate to the CORE One carriage | 6061-T6 | CNC milling | flatness 0.05 mm; K3D40 M3 pattern ±0.05 mm | machine shop | USD 100–350 |
| CFRP platen 80 × 60 × 1.5 mm (`platen_cfrp`), paper edge clamps (`clamp_nx`, `clamp_px`) | CFRP; PETG | waterjet or CNC routing by a supplier (CFRP dust); FDM | ±0.2 mm | supplier + hobbyist | USD 20–100 |

The head plate is taken from the CORE One's published CAD (AMF-231 says the CAD is published). No drawing of it exists in this repository.

### 4.3 Instruments and tools

- K3D40 ±2 N; LSB200 100 g; DAQ-1.
- Dead weights, pulley and inclinometer.
- The scanner with a USAF-1951 target.
- Thermocouples for room and paper temperature.
- Standard build adds the LM13 encoders, the voice coil, the ±10 N plate and the 250 g axial cell.

### 4.4 Assembly

1. **Printer.** Build the CORE One+ kit by the maker's manual and run its self-test.
   - Leave the extruder's electronics connected but park the extruder off the carriage on a bracket.
   - Its thermistors then read room temperature, and the heater targets stay at 0 (PROPOSED).
   - Confirm that the printer's firmware accepts this; the firmware is open source (AMF-231).
2. **Plate stack.** Fit the bed adapter on the bed, then the K3D40 ±2 N, then the CFRP platen. Put an underlay under the paper (glass, pad or elastomer) and clamp the paper at its edges.
3. **Head.** Fit the head plate on the X carriage, then:
   - the tilt arc and carriage;
   - the cartridge frame with both leaves clamped flat and parallel;
   - the holder, collet and refill;
   - the LSB200 in line behind the holder;
   - the magnet on the slide and the DRV5055 on its bracket.
   In the first build, the refill force comes from a thread over the jewel-bearing pulley to a dead weight. The standard build replaces this with the voice coil.
4. **Wiring.** Route the cables through the printer's cable path with strain relief. The cell's cable must not load the axial path; the guide-stiffness calibration includes whatever it adds.
5. **Channels.** Wire the bridges to the ADC channels as `rig.convert.CHANNEL_MAPS['R9']` expects:
   - ch0: axial cell;
   - ch1–3: plate x, y, z;
   - ch4: coil shunt;
   - ch5: slide Hall.
6. **Stroke timing.**
   - Standard build: the encoders give position.
   - First build: a printer output toggled from the G-code at each stroke start, for example the part-cooling fan output through an optocoupler, goes to the marker input (pin 32). The head position is then rebuilt from the commanded path. Check that the CORE One's firmware can do this; no helper for this exists yet (§10.2).
7. **Checks** (checklist C):
   - tilt at each angle under load;
   - clearances at every tilt (the CAD's fit checks: 9.7 mm at 35°);
   - guide stiffness;
   - axial cell and plate calibrations at each test angle;
   - tap test of the plate stack.

### 4.5 What the first build gives up

The first build can still answer G1's two main questions: F_c,min per refill and paper, and the side load at 35, 50 and 75°.

| Standard feature | First-build version | Consequence |
|---|---|---|
| Voice-coil F_c | dead weights | only fixed-force lines, no ramps: EXP-T02's threshold comes from the lines around it, which the protocol uses to confirm the ramp anyway; no modulation, so AC-T02-03 waits for the voice coil |
| LM13 encoders | commanded path plus marker | AC-BB02-02 (speed stability) and per-sample friction ripple wait for the encoders |
| ±10 N plate and 250 g axial cell | ±2 N plate and 100 g cell (F_c ≤ 0.5 N, the rig design's limit for that cell) | N reaches about 0.5 N at 75° and 0.7 N at 35° in every stroke direction (CALCULATION, N = F_c / (sin θ − μ cos β cos θ) with μ 0.15; `bench_calcs.json → r9_normal_force_reach`). That covers EXP-T01's grid (F_c 0.08–0.30 N) but not AC-B01-20's 0.2–2.0 N envelope, which waits for the 250 g cell and the ±10 N plate. EXP-B01's 4 N level needs a larger axial cell still (open item of `prototype_stages.md` §0) |

### 4.6 Safety

- **Pinch points.** The printer's belts and gantry are enclosed; close the door while the head moves. The printer's stop and power switch are the emergency stop.
- **Heat.** The bed and hotend heaters are never on. The chamber reaches up to 55 °C in thermal runs (AMF-231), so its surfaces are hot then.
- **Glass.** Edge-ground underlays only.
- **Dust.** CFRP dust: the platen is cut by a supplier.
- **Weights.** Keep the dead weights clear of the moving head.

---

## 5. B2: the G2 coupons

The five coupons below answer the G2 items of the brief. Each comes with its experiment, its fixture and its instruments. The full lines are in `bom_B2_g2_coupons.csv`.

### 5.1 Force-constant coupons (EXP-T07 with study K's EXP-K22; the reach candidate's winding)

**What is built.** Two translation coupons on the R12 bench (`docs/measurement_rig.md` §5, used with its goniometers locked). In each, a stator holds four N52 poles, the back iron and the keeper, at the model's gaps: 0.3 mm from magnet to coil and 0.15 mm from coil to keeper. The stator sits on a K3D40 ±10 N. The moving coil pack rides on an arm through the keeper's hole and is set by a manual XYZ stage.
- **Rev K coil** (DEC-062; study K's EXP-K22):
  - concentric racetracks, bundles 2.2 mm wide, rows 5.0 mm off the axis;
  - study B's poles are 5.12 × 5.12 × 3.5 mm (`results/bnib/bnib.json`, recommended design);
  - prediction 0.334 / 0.272 N/√W for the x and y layers at the centre (CALCULATION, `docs/revK_design.md` §3.3).
- **Reach candidate** (DEC-072 (a)):
  - poles 4.81 × 4.81 × 3.5 mm;
  - two 0.8 mm winding layers (x then y), bundles 2.2 mm wide, rows 4.75 mm off the axis;
  - weakest sampled force constant 0.158 N/√W (CALCULATION, `results/improvement/mechanics/mechanics_study.json`).

**Stock magnets first (DEC-095 proposed).** The design sizes are not stock items. The first coupons use stock stand-ins, and the models are re-run at the as-built size and measured Br before comparison (`bench_protocols.md` §0.2):
- 5 × 5 × 3 mm N52, ±0.1 mm, supermagnete Q-05-05-03-N52N: EUR 0.35 each at 20, 2,120 in stock (MANUFACTURER, AMF-309);
- 4.76 mm N52 cubes, K&J B333-N52: USD 0.56 each, in stock, Br 14,800 G on the page (MANUFACTURER, AMF-310).

Custom poles are ordered only after AC-T07-02 passes on the stock coupon: USD 150–600 per batch and 4–8 weeks (ASSUMPTION).

**Fabricated parts.**

| Part | STEP source | Material, process | Tolerance | Who, cost |
|---|---|---|---|---|
| Back iron 0.5 mm and keeper 0.3 mm rings (reach: R 10.6/3.6 mm); Rev K's back plate and keeper, and the heel variant's 1.2 mm notched pair | `extended_reach_nib.step` (`back_iron`, `keeper_with_front_race_surface`); `revK_pen_assembly.step` (`back_plate`, `keeper`) | 1008/1010 sheet; wire EDM or fibre laser, deburr, stress relief | ±0.02 mm, flat to 0.02 mm | laser/EDM service, USD 60–300 (ASSUMPTION) |
| Bonded racetrack coil packs, 2–4 sets | `extended_reach_nib.step` (`winding_pack_*`); `revK_pen_assembly.step` (`coil_x`, `coil_y`) | self-bonding enamelled wire, wound on a split mandrel, heat- or solvent-bonded | layer thickness ±0.03 mm | coil-winding service, USD 300–1,500, 3–6 weeks (ASSUMPTION); or wound by hand by a skilled hobbyist with bondable wire (USD 20–60) |
| Stator block with magnet pocket and keeper spacer; coil arm | `rig_coupon_assembly.step` (`base_plate`, `bridge`, `stator_plate`, `coupon_arm`) | 6061-T6 CNC; PEEK or SLA resin arm | ±0.02 mm on gap-setting faces | machine shop, USD 200–700 (ASSUMPTION) |

**Instruments.**
- K3D40 ±10 N.
- XYZ stage with 13–25 mm travel and 10 µm graduation: USD 400–1,600 (ASSUMPTION; Thorlabs' pages showed no price here).
- DAQ-1 with the OPA548 or OPA564 current drive.
- A 4-wire DMM for R20 and an LCR meter for L (USD 100–600, ASSUMPTION).
- Thermocouple on the coil.

**Assembly.**
1. Measure every magnet: dimensions, and Br by a pull test or a Gaussmeter. Mark the polarities.
2. Place the four poles in a checkerboard in the pocket one at a time, with a brass jig and eye protection. Bond them, and fit the back iron and the keeper spacer.
3. Mount the coil pack on its arm, and the arm on the XYZ stage.
4. Centre the coil by the symmetry of the zero-current force, to within 0.05 mm (the tolerance of DEC-044).
5. Map 7 × 7 (or 11 × 11) nodes over ±1.2 mm (Rev K) or ±1.5 mm (reach), with currents in reversal order (EXP-T07's procedure).

EXP-T08's keeper pull (AC-T08-01, 9.1 N predicted, to within ±20 %) needs a sensor rated above about 11 N, such as R12's K3D40 ±50 N, which is not in this BOM. It waits for the next build (§13).

**Criteria.** AC-T07-01 to AC-T07-05 (§8).

### 5.2 Wire coupons and the fatigue shuttle (EXP-K21; EXP-BB04 proposed)

**Wire.**
- **Rev K** (EXP-K21): four 0.10 mm C17200 wires of 26.8 mm, which carry the coil current (DEC-063); a 0.08 mm variant for comparison.
- **Reach candidate** (EXP-BB04): eight 0.10 mm wires of 34 mm, two in parallel per lead, with a 1.7 mm stop and an axially soft anchor of about 100 N/m. Its stress calculation assumed a total axial stiffness of 80–120 N/m and at most 5 mN of assembly tension.

**Source.** Goodfellow's Cu98/Be2 wire (AMF-311):
- spooled wire "starting at $279.00", about 2 weeks' lead time;
- straight wire of 1 m, hard temper, "starting at $429.00".

The diameter table did not load, so ask for a quote that confirms 0.10 and 0.08 mm in an aged temper (TH04/HT or AT). Condition data are in AMF-18 and AMF-19; conductivity in AMF-251.

**Fatigue drive frequency (CALCULATION, `results/benchbuild/bench_calcs.json`).** The first transverse mode of a clamped wire, by the Rayleigh method with E 127.6 GPa and density 8.26 g/cm³ (MFR AMF-19):

| Wire | First mode | 0.2 × first mode | Clamp stress rise at 200 Hz | 43.2 M cycles at 0.2 × first mode |
|---|---|---|---|---|
| 34 mm | about 336 Hz at 5 mN tension; 373 Hz at 11 mN | 67–75 Hz | about 90 % (66 % at 11 mN) | 160–180 h |
| 26.8 mm | about 487 Hz without preload; 763 Hz at 0.05 N | 97–153 Hz | 12–33 % | 80–125 h |

The clamp stress rise is a single-mode estimate of base excitation, and is an ASSUMPTION. `validation/bench_protocols.md` gives EXP-B25's fatigue step as "about 60 h at 200 Hz", and EXP-K21 cycles its coupons "as EXP-B25" (AC-K21-02). At that frequency the wire's own dynamics would inflate the stress the pen never sees, because the pen moves at tremor frequencies of 12 Hz or less. The plan therefore:
- measures each coupon's first mode before cycling (`templates/wire_mode_check.csv`);
- drives at no more than 0.2 × that mode (AC-BB04-05; DEC-098 proposed);
- runs several coupons in parallel.

**The fatigue shuttle (PROPOSED DESIGN, no CAD).** A crank-eccentric drive moves a leaf-guided shuttle through the stop travel: 1.26 mm for Rev K, 1.7 mm for the reach candidate. The shuttle carries six or more coupon stations.
- The protocol's R8 stations call for laser amplitude control. A ground eccentric sets the amplitude geometrically (±0.01 mm), so it needs no loop.
- Each wire carries 0.1 A from an eight-channel constant-current source (REQ-RVK-004). Its 4-wire resistance is logged on the ADS131M08.
- A failure is an open circuit or a step of more than 2 % above the running median (`tools/pipeline_check.py → wire_failure`). This replaces resonance tracking.
- The shuttle needs a balanced crank and a guard.
- Cost: shop USD 300–1,200, drive motor USD 40–200, current source USD 30–100 (ASSUMPTION).
- Optional: a Panasonic HG-C1030 laser sensor to check amplitude and measure the first mode, USD 439.60, 26 in stock (MANUFACTURER, AMF-318). The strobed camera of B4 can do the same.

**Clamps.**
- Brass solder clamps with a 0.12 mm slot and a polished exit radius of 0.10 ± 0.02 mm, which sets Kt. Crimp tubes of 304 hypodermic tube are the alternative.
- Machine shop with wire EDM, USD 200–700 (ASSUMPTION).
- **Kt cannot be measured with a gauge on a 0.10 mm wire.** The plan proposes 10× scaled coupons: 1.0 mm C17200 in scaled clamps with 0.2 mm-grid gauges. Kt depends on the geometry, so it scales (§13).

**Assembly** (checklist F):
1. Cut the wire with shears or flush cutters and wipe it with IPA.
2. Solder it into the clamp under the fume absorber, with gloves, while a fixture holds it straight and without tension.
3. Inspect the clamp exit at 50×.
4. Measure R20 by 4-wire. Mount the coupon on the shuttle and measure its first mode.
5. Set the stroke and start the cycling, with the current on.

**Criteria.** AC-K21-01…04; AC-BB04-01…05 (§8, §14).

### 5.3 Ball-guide coupons (EXP-K20; EXP-BB05 proposed)

**What is built.**
- **Rev K's guide:** the carrier flange (18.9 mm diameter) between two lapped 440C races on 2 × 6 Si3N4 balls of 0.8 mm, on a 16.6 mm circle. Each race sits on a wave spring preloaded to 4 N. The couple is 10.9 mN·m at 35° (CALCULATION, `docs/revK_design.md` §3.3).
- **The reach candidate's full-ring guide:** a 15.1 mm ball circle and 2.9 mm races on the same balls. At the 4 N preload the pass calculates 8.07 mN of rolling drag and 2.64 GPa of peak Hertz pressure (CALCULATION, `docs/mechanics_improvement_audit.md`).

Both figures use a rolling coefficient of 0.001 (ASSUMPTION). The drag is above EXP-K20's 5 mN line, so EXP-BB05 steps the preload through 1, 2, 3 and 4 N, and looks for a preload that holds the carrier's tilt within 0.2 mrad (REQ-RVK-003) with no more than 5 mN of drag.

**Fabricated parts.**

| Part | STEP source | Material, process | Tolerance | Who, cost |
|---|---|---|---|---|
| Races: Rev K's ×3, the reach candidate's ×3; race inserts for the flange ×4 | `revK_pen_assembly.step` (`front_race`, `rear_race`); `extended_reach_nib.step` (`rear_race`, `keeper_with_front_race_surface`) | 440C: turn, harden (HRC 58–60, ASSUMPTION), grind, lap | flat ≤ 1 µm, parallel ≤ 2 µm, Ra ≤ 0.05 µm (ASSUMPTION specification) | precision grinding shop, USD 400–1,500, 3–6 weeks (ASSUMPTION) |
| Carrier flanges: Rev K 18.9 × 1.5 mm, reach 18 × 1.5 mm; one with 440C inserts, one with a bare titanium face | `revK_pen_assembly.step` (`carrier_flange`); `extended_reach_nib.step` (`moving_flange`) | Ti-6Al-4V CNC turning, faces lapped | faces parallel ≤ 2 µm; thickness ±0.005 mm | machine shop, USD 150–600 (ASSUMPTION) |
| Drop rig: a 1 m tube and a dummy pen carrying the guide | PROPOSED | PETG, acrylic | ±0.3 mm | hobbyist, USD 30–100 |

**The flange face.** In the CAD the balls run directly on the titanium flange. The calculated 2.6 GPa Hertz stress is well above Ti-6Al-4V's 0.91–1.11 GPa yield strength (LIT AMF-20), so the face is likely to indent (ASSUMPTION). The coupon therefore tests hardened inserts against a bare face (AC-BB05-03).

**No ball retainer.** The CAD has none. The coupon starts without a cage and records whether the balls migrate (§13).

**Purchased parts.**
- Si3N4 balls, 0.8 mm, grade 5: USD 0.2–0.8 each (ASSUMPTION: Ortech lists the size but shows no price).
- Wave springs of about 4 N, several rates: USD 4–15 each (ASSUMPTION).

**Instruments.**
- **Drag:** a 10 g (0.1 N) FUTEK LSB200 FSH03867, USD 450–900 (ASSUMPTION; AMF-225). The K3D40 cannot judge a 5 mN line: its test uncertainty ratio is 0.56–0.71, against 12–15 for the 10 g cell (CALCULATION, `bench_calcs.json`).
- **Preload:** the K3D40 ±10 N (its Fz channel).
- **Tilt:** a laser lever (diode laser and position-sensitive detector), USD 300–900; an autocollimator costs USD 3,000–8,000 (ASSUMPTION).
- **Race profilometry:** a metrology lab, USD 100–400 per session (ASSUMPTION).

**Assembly.**
1. Clean the races and balls with IPA.
2. Stack them in this order: lower race on its wave spring over the K3D40, balls, flange, balls, upper race on its wave spring.
3. Set the preload with a micrometer screw while reading Fz.
4. Apply the couple with a dead weight on a lever.
5. Sweep ±1.26 mm (Rev K) or ±1.5 mm (reach) at 8 Hz through the 10 g cell.
6. Compute the drag as half the forward-minus-return force at the same position (`tools/pipeline_check.py → guide_drag`).

### 5.4 The floating-anchor coupon (EXP-BB03 proposed)

**What is built.** The pass's axially soft anchor is four fixed-guided beams, 6 × 0.5 mm, in 35 µm full-hard 301 foil (`results/improvement/mechanics/floating_anchor_coupon.step`). The beams alone are calculated at 76.6 N/m (CALCULATION, E 193 GPa ASSUMPTION). The flexible interconnect is budgeted at about 23.4 N/m, for 80–120 N/m in all.

**Thickness sensitivity (CALCULATION, `bench_calcs.json`).** The beam stiffness goes as w t³ / L³, so a ±1 µm thickness error moves it by ±8.6 %. A 35 µm foil is not a US shim gauge. At 0.5 mm beam width:

| Foil | Stiffness | Beam width that gives 76.6 N/m |
|---|---|---|
| 25.4 µm | 29.3 N/m | 1.31 mm |
| 30 µm | 48.3 N/m | 0.79 mm |
| 35 µm | 76.6 N/m | 0.50 mm |
| 38.1 µm | 98.8 N/m | 0.39 mm |
| 40 µm | 114.4 N/m | 0.34 mm |

The foil is therefore measured at five points on each sheet, and the artwork's beam width is set from that measurement. The beams' bending stress at the 50 µm anchor motion is 28 MPa, far below 301 full-hard's 540 MPa fatigue strength (CALCULATION; LIT AMF-20).

**Process.** Precision photochemical etching or UV-laser micromachining, holding the beam width to ±0.01 mm: USD 300–1,500 for a first batch, 2–4 weeks (ASSUMPTION). A service with ±0.13 mm and a 1 mm minimum feature cannot make these beams, for example Ponoko (MANUFACTURER, AMF-313).

**Materials.**
- Foil: Goodfellow AISI 301, hard, "$252.00" starting price; the thickness band 0.01–0.05 mm appears in its tolerance table (MANUFACTURER, AMF-312).
- Interconnect: a polyimide flex board from a prototype service, USD 50–300 (ASSUMPTION).

**Measurement.** The anchor's frame sits on a precision balance with at least 1 mg readability (USD 200–2,500, ASSUMPTION). A 1 µm micrometer pushes the hub 0–100 µm in 10 µm steps. The stiffness is the slope, fitted by `rig.calib.fit_guide_stiffness`. The pipeline check recovered 96.0 against 96 N/m (SIM). The measurement is repeated with the interconnect fitted. The wires' assembly tension is the hub's offset times this stiffness (AC-BB03-03, at most 5 mN).

### 5.5 The counter-face bench (EXP-J17 part (c)) on R9's frame

**What is built.** Study B's face is carried on R9's tilt arc: a 6 mm hardened disc on a cross-strip flexure, a constant-force strip spring, a follower stop, and a rolling refill guide in a carrier.
- A second K3D40 ±2 N sits under the carrier and measures the residual side load (USD 900–1,900, ASSUMPTION).
- The protocol's six-axis ATI Nano17 would also give the couple: USD 5,000–9,000 (ASSUMPTION; AMF-223, price not seen).
- Release and return are timed from the carrier's force at 4 kSPS.
- The inputs are three refills and F_s of 0.1–0.7 N.

**Missing CAD.** This fixture has no CAD (§13). Its parts are a shop job: USD 300–1,000 (ASSUMPTION).

**What it decides.** Its residual load and friction are the measured inputs that DEC-072 and DEC-096 need (AC-J17-04…07).

**Rev K's head.** Rev K's head mock-up (EXP-K23) waits for its motors, or for the micro-stepper lead-screw fallback of DEC-064.

### 5.6 Safety for B2

- **Beryllium copper** (DEC-063; DEC-097 proposed; AMF-18, AMF-319, AMF-320).
  - The wire arrives already aged; no heat treatment is done at the bench.
  - Cut with shears or flush cutters only: no abrasive cutting, grinding, sanding, pickling or acid cleaning.
  - Solder under the fume absorber, or crimp. Nothing is welded.
  - Wear gloves: the SDS lists skin sensitisation among the hazards, and a 0.1 mm sliver can pierce skin (AMF-319). Wear eye protection.
  - Bag and label offcuts, broken coupons and wipes. No food or drink at the bench; wash hands after handling.
- **Magnets.** N52 blocks snap together: assemble them one at a time in a non-magnetic jig, with eye protection against chipped magnet. Keep them away from pacemakers and from magnetic media. The heated runs stay below the supplier's stated maximum temperature, which has not yet been read.
- **Fatigue shuttle.** The eccentric turns at 4,000–9,000 rpm: guard it, and balance the crank.
- **Drops.** Balls and fragments fly: wear eye protection.
- **Foil.** Etched foil edges are sharp: wear gloves.

---

## 6. B3: the grounded five-bar demonstrator

**Design** (the pass; `mechanics/cad/grounded_stage.py`, `wholepen/grounded.py`; all CALCULATION or ASSUMPTION).
- **Geometry.** Two motors on a desk-mounted base 50 mm apart. Proximal links are 60 mm and distal links 90 mm. The writing patch is 60 × 40 mm, centred 90 mm from the motor line.
- **Drive.** 6:1 capstans: an 18 mm output radius driven from a 3 mm motor radius. The 80 % efficiency is an ASSUMPTION.
- **Motors.** Faulhaber 2224 U 012 SR: 6.21 mN·m rated torque, 14.6 mN·m/A, 8.77 Ω (the pass's datasheet reading).
- **Force.** The continuous force disk has a sampled minimum of 0.480 N. The controller's cap is 0.4 N, an ASSUMPTION rather than a clinical limit. Reflected mass is 93–105 g.
- **Encoders.** The model assumes 16-bit output encoders. The build uses 14-bit AS5047P encoders, which quantise the endpoint to 8.0 µm (1σ, worst case) against 2.0 µm at 16 bits (CALCULATION, `bench_calcs.json`).
- **Force at rated current.** With both motors at rated current, the linkage can push up to 1.06 N at its worst pose and direction (CALCULATION). The 0.4 N cap is therefore software, and a breakaway coupling is the physical backstop (DEC-099 proposed).

### 6.1 Purchased parts

| Part | Manufacturer part number | Supplier | Unit price, date, stock (label, ledger) | Qty |
|---|---|---|---|---|
| Brushed coreless motor, 22 mm, 12 V | Faulhaber 2224U012SR; the DigiKey listing's manufacturer number is "2224.11000" | DigiKey marketplace (5293-2224.11000-ND) | USD 122.60, 7 in stock, "ships in approximately 5 days from Faulhaber", USD 9 shipping (MANUFACTURER, AMF-304) | 3 (one spare) |
| Output-shaft encoder, 14-bit, on adapter board | ams AS5047P adapter board | DigiKey (4991-AS5047PADAPTERBOARD-ND) | USD 19.40, 397 in stock; the AS5047P IC itself is listed as discontinued (MANUFACTURER, AMF-307) | 3 |
| Motor driver with current sense (1.1 V/A) | Pololu 4035 (DRV8874 carrier) | pololu.com | USD 11.94 (MANUFACTURER, AMF-305); alternative maxon ESCON Module 24/2 (466023), EUR 97.68, NRND, current-controller mode (AMF-306) | 3 |
| Bearings 3 × 6 × 2.5 mm | MR63-ZZ | Bearings Direct | USD 4.38 each, 684 available, ships in 24 h; ABEC grade not stated (MANUFACTURER, AMF-316) | 12 |
| Controller board | Teensy 4.1 | SparkFun (DEV-16771) | USD 31.50 (MANUFACTURER, AMF-220) | 1 |
| 12 V 60 W supply | Mean Well GST60A12-P1J | DigiKey | USD 19.40 (MANUFACTURER, AMF-308) | 1 |
| Diametric encoder magnets; 3 mm h6 shafts; capstan cable (Dyneema or 7×7 stainless) and tensioners; latching emergency stop and relay; micro-servo pen lift; 200 and 500 N/m springs on a linear guide | class | any | USD 2–8 each; 15–40; 15–50; 25–80; 8–25; 20–80 (ASSUMPTION) | as needed |

Confirm before ordering that DigiKey's "2224.11000" is the 2224 U 012 SR. RS 873-4795 lists the 2224U012SR at 12 V, 6.7 mN·m and 4,390 rpm, the same speed as DigiKey's listing (AMF-304).

### 6.2 Fabricated parts

All are taken from `results/improvement/mechanics/grounded_fivebar.step`.

| Part (solid names) | Material, process | Tolerance | Who, cost (ASSUMPTION) |
|---|---|---|---|
| Base 170 × 165 × 5 mm (`desk_reaction_base`) | 6061-T6 plate; waterjet and CNC finishing | bores ±0.02 mm; base spacing 50.00 ± 0.02 mm | machine shop, USD 80–300 |
| Output bearing supports ×2 (`output_bearing_support_0/1`) | 6061-T6, lathe | bearing bores H7; coaxial to 0.01 mm | machine shop, USD 60–200 |
| Capstans: output R 18 mm ×2, motor R 3 mm ×2 (`output_capstan_*`, `motor_capstan_*`) | 6061 output drums with a helical cable groove; brass motor drums with a 2 mm bore | groove pitch ±0.02 mm | machine shop, USD 80–300 (a printed first try is possible) |
| Links: 60 mm ×2 and 90 mm ×2, 7 × 3 mm (`proximal_link_*`, `distal_link_*`) | 6061-T6 or CFRP plate, waterjet or CNC | pin centres ±0.02 mm; bearing seats H7 | machine shop, USD 60–250 |
| Pen holder for a 24 mm dummy pen: breakaway magnetic coupling releasing at 0.5–0.8 N, lift guide, dummy pen with refill and brass ballast (from the keep-out solid `24mm_pen_holder_keepout`) | PETG or SLA resin; N52 discs | ±0.1 mm | hobbyist, USD 30–120 |
| Guards over the capstans and the sweep of the links | laser-cut acrylic | ±0.3 mm | hobbyist, USD 20–60 |

The pass's CAD leaves several things unresolved, and they are resolved during this build: the cable routing and tensioner, the output encoder mounts, the bearing preload, the pen gimbal and lift, and the emergency force release.

### 6.3 Instruments

- The K3D40 ±10 N from B1, for the force map and the force cap.
- The OV9281 camera with a dot grid from B4, as endpoint truth.
- DAQ-1, which receives the controller's clock through the sync pulse.
- The oscilloscope.

### 6.4 Assembly

1. Press the bearings into the links and supports, and fit the h6 shafts.
2. Mount the motors on the base and fix the motor drums on the 2 mm shafts.
3. Wind each capstan cable with a fixed number of turns, anchor it at both ends, and pretension it with the tensioner.
4. Fit the diametric magnets on the output shaft ends, and the AS5047P boards below them at the air gap the data sheet gives.
5. Assemble the four links and the pen holder, with the breakaway coupling, the lift servo and the dummy pen.
6. Electronics:
   - the controller Teensy, two DRV8874 carriers and the 12 V supply, with the emergency-stop relay on the motor supply;
   - encoders on SPI;
   - DAQ-1's sync pulse into a controller input.
   The controller firmware does not exist yet (§13). It needs current loops using the 1.1 V/A sense output, a Cartesian controller with τ = Jᵀ F, the 0.4 N cap and logging.
7. Before any motion test, run AC-BB06-04 (checklist G):
   - the emergency stop removes motor power;
   - with the holder blocked, the force stays at or below 0.4 N;
   - the coupling releases between 0.5 and 0.8 N.
8. Calibrate the encoder offsets and link lengths on 20 camera poses, then judge on 35 others (AC-BB06-01).

### 6.5 Safety

- **Pinch points** at the capstans and the link sweep: fit guards, and keep hands out of the workspace while the motors are enabled.
- **Stops.** A latching emergency stop. The hardware current limit is at rated current, with the 0.4 N cap in software and the breakaway coupling as backstop.
- **No person's hand** is used until a safety gate like G-S is written for this device (DEC-099 proposed; `prototype_stages.md` §1 principle 4).
- **Hand simulants.** Springs of 200 and 500 N/m stand in for a resisting hand, as in the pass's simulation.

---

## 7. B4: R10, the page-sensing rig

**Design** (`docs/measurement_rig.md` §3; `mechanics/cad/rig_pagesense.py`). The sensor fixture rides on R9's CoreXY head in place of the contact head:
- a tilt arc of R 45 mm (30–88°);
- a roll ring of ±20°;
- a micrometre Z stage for fine height.

The paper lies on 5 mm float glass. Mode A holds the bare die and lens on a 14 × 12 mm sled. Mode B holds a printed mock nose.

**Truth.** The first choice is the strobed OV9281 camera at 100 fps. It is enough for 10 ms windows: TUR 4.8 against 10 µm, resting on an ASSUMED centroid noise until qualified (`docs/measurement_rig.md` §3.4). The standard build adds R9's LM13 encoders for per-sample noise.

### 7.1 Parts

| Part | Manufacturer part number | Supplier | Price and availability (label, ledger) | Qty |
|---|---|---|---|---|
| PAA5100JE breakout (15–35 mm) | Pimoroni PIM573 | shop.pimoroni.com | "Pre-order", no price shown: USD 20–35 (ASSUMPTION; OPT-90) | 1 |
| PMW3360 breakout with lens | Keycapsss KC10125 (PMW3360DM-T2QU) | keycapsss.com | EUR 29.90 incl. VAT, "Currently out of stock" (MANUFACTURER, OPT-100) | 2 |
| Rev K's die class: PMW3610DM-SUDU with lens, on a small assembled board | PixArt PMW3610DM-SUDU | JLCPCB assembly (C42442560, "Extended" part) | no price or stock shown: USD 35–145 (ASSUMPTION; OPT-101, OPT-61) | 3 |
| Fallback: a commercial mouse with a known sensor, board harvested | class | any | USD 20–80 (ASSUMPTION) | 1 |
| Global-shutter camera with external trigger | Arducam OV9281 UVC (B0332) | arducam.com and resellers | USD 45–80 (ASSUMPTION: the pages returned HTTP 403; OPT-88 documents the trigger mode) | 1 |
| LED strobe; chrome-on-glass dot grid; Z micrometre stage; float glass, glossy strip, printed fiducial sheets | class | any | USD 10–30; 150–600; 100–600; 15–60 (ASSUMPTION) | 1 each |

### 7.2 Fabricated parts

| Part | Source | Material, process, tolerance | Who, cost (ASSUMPTION) |
|---|---|---|---|
| Tilt arc R 45, arc carriage, roll ring, head plate | `rig_pagesense_assembly.step` (`tilt_arc`, `arc_carriage`, `roll_ring`, `head_plate`) | PETG or PA-CF by FDM, and a 6061 plate; ±0.1 mm | hobbyist + shop, USD 30–200 |
| Mode A sled; Mode B mock nose | `rig_pagesense_sled_assembly.step`; `rig_pagesense_assembly.step` (`mock_nose`) | SLA resin, ±0.05 mm | hobbyist or online, USD 20–80 |
| Latency step flexure: 50 µm steps with ≤ 0.5 ms rise, driven by R9's LVCM-013 voice coil | PROPOSED DESIGN (no CAD) | spring-steel leaves, 6061 block | shop, USD 50–200 |

The step flexure is needed because EXP-T05 names R13's stage as its step source, and R13 is not in this build (§13).

### 7.3 Assembly and safety

**Assembly.**
1. Take R9's contact head off and fit R10's head plate. The two rigs share the frame in turn.
2. Fit the glass platen on the bed adapter and clamp the paper, the glossy strip and the fiducial sheet.
3. Put the sensor on the sled (Mode A). Mount the PAA5100JE on a flat plate at 15–35 mm.
4. Wire SPI1 to DAQ-1.
5. Mount the camera on a bracket looking at a dot beside the sensor window, with the strobe on pins 24/25.
6. Qualify the camera first, on a static dot grid.

**Safety.** The mouse-sensor lasers are low-power; still, do not look into the window. Keep the printer door closed while the head moves.

---

## 8. Test sequence and the decisions it feeds

`results/benchbuild/test_decision_map.csv` holds the full map; this is the summary. The "gate" column names the gates of `validation/prototype_stages.md` §0.

| Build | Experiment | Criteria and pass/fail line | Feeds | If it fails |
|---|---|---|---|---|
| B0 | EXP-BB01 (proposed) | AC-BB01-01…05: 0 CRC errors and 0 missing frames in 10 min at 8 kSPS; ADC noise ≤ 2.4 µV; sync residual ≤ 50 µs; 0 encoder counts lost; current step ≤ 2 ms | DEC-058 (one clock); order 0 of every gate | fix firmware or wiring before any record |
| B1 | EXP-BB02 (proposed) | AC-BB02-01: plate stack first mode ≥ 100 Hz. AC-BB02-02…04: speed, plate residual, guide stiffness | DEC-058's revisit trigger; validity of G1 | stiffen the stack or use the ±10 N plate; persistent failure reopens DEC-058 |
| B1 | EXP-T02 | AC-T02-01: F_c,min ≤ 0.3 N for Rev K's refill everywhere. AC-T02-02: U ≤ 12 mN. AC-T02-03: gaps ≤ 1 % under modulation. AC-T02-04: report per tip type and paper | DEC-050 (the F_s set point; revisited above 0.3 N); REQ-BNIB-014; G1 | another refill; above 0.3 N, DEC-050's revisit |
| B1 | EXP-T01 | AC-T01-01: closure ≤ max(3 mN, 3 % F_c). AC-T01-02: U(N) ≤ 5 mN. AC-T01-04: μ 0.09–0.40. AC-T01-05: side friction ≤ 0.2. AC-B01-03: P-6 within ±15 % in ≥ 90 % of strokes. AC-B01-20: the 0.2–2.0 N envelope covered, which needs S1's 250 g cell and ±10 N plate | DEC-058; study B's balance range; config/nib.yaml (DEC-050); DEC-066 (pre-sliding stiffness); G1, G-B | recalibrate; replace the contact model and re-run the predictions |
| B1 | EXP-BB09 (proposed) | AC-BB09-01…03: contact-channel delay ≤ 5 ms (99th percentile); ≤ 0.1 false events per minute; lift command to ink stop ≤ 50 ms | DEC-070 (the contact model); DEC-071 (lift) | change the contact channel's threshold and filtering; a faster lift |
| B2 | EXP-J17 (c) | AC-J17-04: residual ≤ 10 % mean and ≤ 25 % at the 95th percentile. AC-J17-05: release ≤ 10 % within 20 ms; touchdown travel. AC-J17-06: guide μ ≤ 0.01. AC-J17-07: ink force ±20 % | DEC-050, DEC-064; the measured load for DEC-072 through DEC-096; G1 (`prototype_stages.md` §0 lists EXP-J17 under G1); "Build the Rev K pen" (AC-J17-04) | the clutched bias b', then the unbalanced nib f (DEC-050) |
| B2 | EXP-T07 (with EXP-K22) | AC-T07-01: K_m ≥ 0.7 × the model at every node. AC-T07-05: Rev K's coil ≥ 0.7 × 0.334 / 0.272 N/√W. AC-T07-02…04: model agreement, ripple (predicted to fail), force against back-EMF | DEC-050 (pole size), DEC-062; **"Build Rev K's nib"** | larger poles (the 24 mm bore is the limit); DEC-062 revisited; the firmware uses the measured map |
| B2 | EXP-K21 | AC-K21-01…04: ≤ 0.3 Ω per wire; no failure in 43.2 M cycles at 0.1 A; preload ≤ 0.05 N; Goodman ≥ 1.5 | DEC-063; **"Build Rev K's nib"** | a 0.08 mm wire (which fails 0.3 Ω) or a beryllium-free alloy; DEC-063 revisited |
| B2 | EXP-BB04 (proposed) | AC-BB04-01…05: lead ≤ 0.3 Ω; no failure at the 1.7 mm stop; Goodman ≥ 1.5; heating within ±25 % of the model; drive ≤ 0.2 × first mode | DEC-072 through DEC-096 | the reach candidate is dropped and the 1.059 mm candidate stays |
| B2 | EXP-K20 | AC-K20-01: friction ≤ 5 mN. AC-K20-02: tilt ≤ 0.2 mrad, no wire compressed beyond half its buckling load. AC-K20-03: no race marks after ten 1 m drops | DEC-063; REQ-RVK-003; **"Build Rev K's nib"** | a lower preload or another guide; DEC-063 revisited |
| B2 | EXP-BB05 (proposed) | AC-BB05-01…03: reach drag 5.6–10.5 mN at 4 N; a preload with tilt ≤ 0.2 mrad and drag ≤ 5 mN; no marks on a bare titanium face | DEC-063 (preload); DEC-072 through DEC-096 | hardened flange inserts; another guide topology (study N) |
| B2 | EXP-BB03 (proposed) | AC-BB03-01…03: beam stiffness ±15 % of the calculation; 80–120 N/m with the interconnect; assembly tension ≤ 5 mN | DEC-072 (the soft anchor that replaces Rev K's 10,000 N/m); DEC-063 | re-etch with a corrected width; a softer interconnect |
| B3 | EXP-BB06 (proposed) | AC-BB06-01…04: endpoint ≤ 50 µm RMS; force ≥ 0.40 N; stiffness ≥ 4 N/mm; cap ≤ 0.4 N and release 0.5–0.8 N (guarded) | DEC-071; DEC-099 | 16-bit encoders or a camera-referenced loop; stiffer links; fix the cap before anything else |
| B3 | EXP-BB07 (proposed) | AC-BB07-01…03: ≥ 18 of 20 suffixes meet the grounded gate with no spring hand; ≤ 0.5 mm of ink after a refusal with 200 and 500 N/m springs; acceleration and jerk reported | DEC-071 | the moving-paper platen (study P); a faster, positively sensed lift |
| B4 | EXP-T04 | AC-T04-01: ≥ 1 kHz and ≤ 10 µm RMS. AC-T04-03: truth U ≤ 2.5 µm. AC-T04-05: dropouts ≤ 1 %, none over 300 ms. AC-T04-07: lift cut-off ≥ 2 mm, predicted to fail with a mouse-class die. AC-T04-08: ±20° of roll beside the heel pod, predicted to fail. AC-J10-04: drift and window error by DeltaPen's metric. AC-S01-02: ≤ 5 µm per sample | sensing build gate; DEC-059; DEC-062 (REQ-BNIB-017, the die); DEC-065; "Build the Rev K pen" | another die or optics; external truth stays in the loop; the heel stays a bench module |
| B4 | EXP-T05 | AC-T05-01: latency ≤ 2 ms (99th percentile). AC-T05-02: step rise ≤ 0.5 ms | the estimator's horizon | a faster sensor mode; a stiffer step source |
| B4 | EXP-BB08 (proposed) | AC-BB08-01…03: 0 silent recoveries of the absolute anchor; re-anchored error ≤ 0.1 mm (95th percentile); lost motion reported | DEC-070; DEC-071; REQ-CAP-003 | no accepted writing across an outage without a verified anchor |

**Order of the gates this first build can close.**
- **G1's contact and ink experiments** (EXP-T01 and T02, with EXP-B01's envelope) close at the end of stage S1. G1 also lists EXP-J17: its part (c) runs on R9's frame in S2, while parts (a) and (b) need a built nose or nib, so G1 as a whole cannot close in this build.
- **The G2 part of "Build Rev K's nib"** closes at the end of stage S2. It needs EXP-T07 on the Rev K coil, EXP-K21 with no wire failure, and EXP-K20's friction and drops (`prototype_stages.md` §0).
- **DEC-072's choice** follows DEC-096's rule at the same meeting.
- **"Build the Rev K pen"** cannot close in this build. It also needs EXP-K23 (the head), EXP-T10 on a nib (R13) and EXP-T04's lift result.

---

## 9. Budget and schedule

### 9.1 The minimum viable first build (weeks 0–4)

The first build is DAQ-1 plus R9 with dead-weight F_c, no encoders, a printed arc, the K3D40 ±2 N and the LSB200 100 g. It costs **USD 4,352–7,732** (stage S0 in `cost_schedule.csv`):
- USD 2,220 of it has a seen price (MANUFACTURER);
- the largest ASSUMPTION lines are the K3D40 (900–1,900), the LSB200 (450–900), and the CNC cartridge and bed adapter (250–850).

Add USD 250–650 for a soldering station and hand tools, and a further USD 1,466–1,766 for an oscilloscope, a 4-wire meter and a bench supply if the lab lacks them. With everything, the first build costs USD 6,068–10,148.

It answers:
- F_c,min per refill and paper, at fixed forces (AC-T02-01, AC-T02-04);
- N and friction at 35, 50 and 75° with the axial closure check (AC-T01-01, T01-02, T01-04, T01-05);
- the plate's first mode (AC-BB02-01);
- the contact channel's delay (AC-BB09-01, -02).

### 9.2 Cost per stage

All figures are USD, sums of line ranges from `cost_schedule.csv`.

| Stage | Weeks | What | Core | With instruments if the lab lacks them |
|---|---|---|---|---|
| S0 | 0–2 | orders; pre-registration; DAQ-1 bring-up; printer kit; first-build R9 parts | 4,352–7,732 | 6,068–10,148 |
| S1 | 1–4 | R9 G1 runs, plus the standard upgrades (±10 N plate, 250 g axial cell, voice coil, 2 × LM13, OPA548, CNC arc) | 2,193–5,193 | same |
| S2 | 3–8 | G2 coupons: force maps, wires and shuttle, guides, anchor, counter-face bench | 5,808–17,936 | 6,848–22,976 |
| S2b | 8–12 | custom magnets, only if AC-T07-02 passes | 150–600 | same |
| S3 | 6–12 | five-bar build, EXP-BB06 and BB07 | 987–2,103 | same (reuses B1/B4 instruments) |
| S4 | 6–12 | R10, EXP-T04, T05 and BB08 | 628–2,475 | same |
| **All** | **0–12** | | **13,968–35,439** (without S2b) | **+2,756–7,456** |

### 9.3 Schedule

| Week | Work | Result |
|---|---|---|
| 0 | Pre-register EXP-T01, T02, BB01 and BB02 (§0.2). Request quotes and order: K3D40 ×3, LSB200 (100 g, 250 g and 10 g), LVCM-013, LM13 ×2, coil winding, lapped races, precision etching, the flex interconnect, the aged C17200 wire, stock magnets, page-sensor boards, Faulhaber motors | order book open |
| 1–2 | DAQ-1 bring-up (EXP-BB01); printer kit assembled; first-build R9 parts printed and CNC'd | one clock (DEC-058) |
| 2–4 | R9 qualification (EXP-BB02) as the sensors arrive; EXP-T02 fixed-force lines on 3+ refills × 6 papers × 35/50/75°; EXP-T01 on the nominal pair and a reduced grid; EXP-BB09 | **G1: F_c,min, friction, side load** |
| 3–5 | Wire coupons soldered; first modes measured; fatigue batch 1 (Rev K wires, about 3.3–5 days) | |
| 4–6 | Force-constant coupons with stock magnets (EXP-T07/K22); EXP-J17 (c) on R9's frame; the anchor coupon (EXP-BB03) | K_m map; residual side load |
| 5–8 | Fatigue batch 2 (reach wires, about 7 days); guide coupons once the races arrive (EXP-K20, BB05); drops and profilometry | |
| 6–9 | Five-bar parts and assembly; EXP-BB06 | |
| **8** | **G2 meeting**: the "Build Rev K's nib" inputs; DEC-096's duty re-run with the measured load, K_m, drag and anchor | DEC-062/063 confirmed or revisited; DEC-072 chosen |
| 9–12 | EXP-BB07 (word replay against spring hands); R10 (EXP-T04, T05, BB08) | **the grounded route (DEC-071); the sensing build gate** |

The schedule slips one-for-one with the force-sensor lead time. If the K3D40 or LSB200 lead time is over 6 weeks, start with the low-cost G1 build of `docs/measurement_rig.md` §2.9: TAL221 cells and NAU7802 boards. It still needs a three-axis plate for friction. EXP-T02's ink-force lines need only dead weights and the scanner, so they can run before the plate arrives.

### 9.4 Who can do what

| Task | Skilled hobbyist or small team | Machine shop | Specialist supplier or service |
|---|---|---|---|
| DAQ wiring, firmware upload, printer kit, printed fixtures (arcs, sled, holder, guards), dead-weight calibration, scanning, blind coding, analysis | ✓ | | |
| Cartridge frame, bed adapter, head plates, coupon stator block, five-bar base, supports, capstans and links, clamp blocks (EDM slot), fatigue shuttle, anchor frame, counter-face parts | | ✓ | |
| Lapped 440C races: harden, grind and lap to ≤ 1 µm | | precision grinding shop | |
| Soldering 0.10 mm C17200 into clamps under a microscope; hand-winding a first coil with bondable wire | ✓ (skilled) | | |
| Bonded racetrack coils to ±0.03 mm | | | coil-winding service |
| Aged C17200 fine wire; any heat treatment of it (DEC-097 proposed) | | | wire supplier with beryllium controls |
| Custom magnets | | | magnet maker |
| Anchor beams to ±0.01 mm | | | precision photo-etcher or laser micromachining |
| Flexible interconnect | | | flex-PCB prototype service |
| CFRP cutting | | | supplier (dust) |
| Race profilometry; calibration certificates | | | metrology lab; the sensor makers |
| Laser welding | not used: C17200 is soldered or crimped (DEC-063). Study B's titanium wires (EXP-B25) would need a supplier with fume extraction; they are not in this build | | |

### 9.5 Lead times

| Item | Lead time | Label |
|---|---|---|
| Teensy, ADS131M08EVM, MAX31856, DRV5055, AS5047P boards, DRV8874 carriers, stock magnets, MR63-ZZ, weights, V39 II scanner, Rigol scope | 1–5 days, in stock | MANUFACTURER (AMF-220, 300, 234, 302, 307, 305, 309, 310, 316, 315, 314, 321) |
| Prusa CORE One+ kit | 1–3 business days of preparation, plus shipping | MANUFACTURER (AMF-231) and ASSUMPTION (shipping) |
| Faulhaber 2224 | about 5 days from Faulhaber, DigiKey marketplace | MANUFACTURER (AMF-304) |
| VPG shunt | stock due 12-Oct-2026 | MANUFACTURER (AMF-303) |
| OPA548T | stock due 30-Nov-2026; OPA549T due 02-Dec-2027 | MANUFACTURER (AMF-301) |
| Goodfellow CuBe2 wire | about 2 weeks | MANUFACTURER (AMF-311) |
| K3D40, LSB200, LVCM-013, LM13, Nano17 | 2–6 weeks | ASSUMPTION (quotes) |
| Coil winding; lapped races | 3–6 weeks | ASSUMPTION |
| Precision etching | 2–4 weeks | ASSUMPTION; Ponoko's 10-day minimum applies to a service that cannot make the beams (AMF-313) |
| Custom magnets | 4–8 weeks | ASSUMPTION |
| Page-sensor boards | unknown: PMW3360 breakout out of stock; PAA5100JE on pre-order; PMW3610 not listed by the large distributors | MANUFACTURER (OPT-100, OPT-90, OPT-101) |

---

## 10. Data pipeline

### 10.1 Which script reads which file

Every row below was exercised on synthetic data by `results/benchbuild/tools/pipeline_check.py`, and all 11 steps pass (SIM; `results/benchbuild/pipeline_check.json`; about 3 s). The rig's own checks also pass on this checkout: `python3 -m rig.selftest --no-write` gives 49 of 49, and `python3 -m pytest rig/tests -q -p no:cacheprovider` gives 30 passed (SIM).

| Measurement file (template) | Produced by | Read by | Analysis | Check (SIM result) |
|---|---|---|---|---|
| `raw.bin`, write-once: SAMPLE, EVENT, PAGE and IMU frames with CRC | DAQ-1 firmware over USB; `python3 -m rig.logger --port … --out DIR` | `python3 -m rig.logger --replay raw.bin --out DIR` → `session.npz`, `session.json` (stats, SHA-256) → `rig.logger.load_session` | `rig.convert.to_units(session, CHANNEL_MAPS[rig], cal)` → `events_by_kind` → `split_by_markers` (one record per MARK) | step A: 3,201 samples, 0 CRC errors, 0 missing frames |
| `r9_axial_cell_calibration.csv`, `r9_plate_calibration.csv`, `r9_guide_stiffness.csv` | dead weights and pulls at the test angle | csv | `rig.calib.fit_bridge`, `fit_plate` + `apply_plate`, `fit_guide_stiffness` | step A |
| R9 stroke records | the above | `rig.contact.analyse_stroke(t, F_c, F_plate, xy, θ, φ)` | friction vector, closure, R_⊥/F_c, `p6_check`, `side_load_table`, `balance_range` | step A: μ within 0.8 %, R_⊥/F_c within 0.54 %, closure 0.06 mN |
| s2r-bench-1 records (`manifest.json`, `group/nnnn_k.npz` + `nnnn.json`) | `rig.convert.to_bench` | `s2r.io.load`; the s2r identification (for example `s2r.exp_b01b02`) | — | step A: identical arrays after reload |
| 16-bit TIFF scans + `ink_scan_register.csv` | R3 scanner | PIL → numpy (Pillow comes with matplotlib) | `rig.ink.analyse_line`, `minimum_ink_force` | step B: F_c,min 0.141 against 0.145 N |
| `t07_force_map.csv` | R12 with the coupon | csv → per-node arrays | `rig.coupon.km_map` (and `attraction_fit`, `lateral_stiffness`, `mode_fit`, `tempco`) | step C: K_f within 0.25 % |
| `anchor_stiffness.csv` | balance + micrometer | csv | `rig.calib.fit_guide_stiffness` (the slope is the stiffness) | step D: 95.97 against 96 N/m |
| `guide_drag_sweep.csv` | 10 g cell + stage | csv | `guide_drag()` in `pipeline_check.py`: half the forward-minus-return force | step E: 5.98 against 6.0 mN |
| `k21_wire_log.csv` | current source + 4-wire channels | csv | `wire_failure()` in `pipeline_check.py`: open circuit or > 2 % step | step F: failure found at the right cycle count, no false alarm |
| `thermal_run.csv` | resistance thermometry, thermocouples | csv | `rig.thermal.coil_temperature`, `fit_1node`, `fit_2node` | step G: R12, R2a within 0.7 % |
| `fivebar_encoder_truth.csv`, `fivebar_force_map.csv` | controller Teensy + camera; K3D40 | csv | `fivebar_fk()` in `pipeline_check.py`; `wholepen.grounded.FiveBar.kinematics` (J) | step H: 11.6 µm RMS with 14-bit counts |
| R10 `raw.bin` with PAGE frames + `r10_pose_matrix.csv` | DAQ-1 (page sensor on SPI1) | logger replay → `to_units(CHANNEL_MAPS['R10'])` + PAGE time base | `rig.pagesense.qualify`, `sim2j_page_model`, `patch_sim2j` | step I: latency 1.599 against 1.600 ms |
| Device logs with their own clock (five-bar controller, page-sensor MCU) | the device | csv | `rig.sync.decode_widths`, `fit_clock` | step J: 5.9 µs worst residual |
| `analysis/verdict.yaml` | the analysis | — | `rig.uncertainty.decide` (simple at TUR ≥ 4, guarded otherwise) | step K |

### 10.2 What the check found missing

These are gaps to fill before or while the first data arrive.
1. **ADC delay.** `rig.convert` computes `t_adc_s`, the 375 µs sinc3 delay at 4 kSPS, but does not resample. `rig.contact.analyse_stroke` takes a single time vector, so forces must be interpolated onto the encoder clock first. The pipeline check does this with `np.interp`.
2. **PAGE and IMU frames.** `rig.convert` converts only SAMPLE frames. PAGE and IMU frames must be mapped onto the SAMPLE clock by `(t_cyc − t0)/f_cpu` with the first SAMPLE's `t0`. The check does this in three lines; `rig/` has no helper.
3. **No rig/ function** exists for guide drag, wire-failure detection, five-bar forward kinematics, the wire's first-mode check, or head position from printer move timing (the first build's substitute for encoders). The first three are written and SIM-checked in `pipeline_check.py`. The first mode is predicted in `bench_calcs.py`, but picking it from a measured sweep is not written, and neither is the move-timing reconstruction.
4. **Scans** need a TIFF reader. Pillow is installed with matplotlib but is not pinned in `requirements.txt`.
5. **Firmware.** DAQ-1's firmware has only been checked against stubs, never compiled for the Teensy (`docs/measurement_rig.md` §11 item 3). The five-bar's controller firmware does not exist.

### 10.3 Templates, checklist and notebook

- `results/benchbuild/templates/` holds blank CSVs whose headers match the readers above:
  - instrument register;
  - run order;
  - R9 calibrations and tap test;
  - ink scan register;
  - the T07 force map;
  - the wire mode check and wire log;
  - the anchor;
  - guide drag and tilt;
  - the thermal run;
  - five-bar encoder truth, force map and word replay;
  - R10 pose matrix and re-anchoring trials;
  - contact timing.
- The same folder holds `record_template.yaml` and `verdict_template.yaml`, both following `validation/records/README.md` §3, and `lab_notebook_template.md`.
- `results/benchbuild/first_measurement_checklist.md` takes the first session of each build from paperwork to a signed verdict.

---

## 11. Safety, all builds

No participant takes part in anything in this plan. Every build is bench-only, so gate G-S does not arise; its principle still stands (`prototype_stages.md` §1).

| Hazard | Where | Control | Source |
|---|---|---|---|
| Airborne beryllium from C17200 | wire coupons, clamps | buy aged wire; no in-house heat treatment; shear-cut only; no abrasive cutting, grinding, sanding, pickling or acid cleaning; solder under local exhaust or crimp; never weld; bag and label waste; wash hands; no food at the bench | DEC-063; DEC-097 (proposed); AMF-18; AMF-319 (NGK SDS §2.1, §8: OSHA PEL 0.2 µg/m³, ceiling 2 µg/m³); AMF-320 (OSHA: STEL 2.0 µg/m³, action level 0.1 µg/m³; C17200 with about 2 % Be is not exempt) |
| Skin sensitisation from C17200; slivers of 0.1 mm wire | handling | nitrile gloves; tweezers | AMF-319 (Skin Sens. 1) |
| Flux and solder fumes | all soldering | bench fume absorber; lead-free solder; ventilation | AMF-317 |
| Magnets snapping and chipping; pacemakers | coupons, encoder magnets | non-magnetic jig, one at a time, eye protection; signage; heated runs below the supplier's maximum temperature | ASSUMPTION: the maximum temperature is to be read from the supplier's data |
| Pinch points and entanglement | CoreXY gantry and belts; five-bar capstans and links; fatigue crank at 4,000–9,000 rpm | printer door closed; guards; latching emergency stops; hands out while motors are enabled | DEC-099 (proposed) |
| Unexpected force on a person | five-bar | 0.4 N software cap; rated-current hardware limit (up to 1.06 N possible, CALCULATION); 0.5–0.8 N breakaway coupling; springs instead of hands | DEC-099 (proposed); `bench_calcs.json` |
| Hot surfaces | printer chamber up to 55 °C (AMF-231); coils under current | thermocouples; the 100 °C coil stop rule of EXP-J17; ≥ 30 s cooling above 0.3 I_max (EXP-T07) | `bench_protocols.md` |
| Lasers | HG-C1030 (655 nm), laser lever, mouse-sensor emitters | class 2 or 3R only, with signage; do not look into windows | `bench_protocols.md` §0.10 |
| Sharp edges | etched 301 foil; cut wire; glass underlays | gloves; edge-ground glass | — |
| Dust | CFRP cutting | a supplier cuts it | — |
| Projectiles | 1 m drop tests with 0.8 mm balls | eye protection; a tube guide | — |
| Solvents | IPA; SLA resin | gloves; ventilation | — |
| Electrical | current amplifiers (±15–30 V), mains adapters | certified adapters; heat-sunk amplifiers; current limits below coil ratings | — |

---

## 12. Evidence rows added

The rows are in `results/benchbuild/evidence_rows.csv`. They use the 23-column header of `docs/evidence.csv`, CRLF line endings, and were all retrieved on 2026-09-30.

| Ids | Content |
|---|---|
| AMF-300 | ADS131M08EVM: DigiKey USD 328.11, 2 in stock; TI kit contents |
| AMF-301 | OPA548T back-ordered (DigiKey, TI); OPA549T back-ordered; OPA564 USD 9.51 |
| AMF-302, 303 | DRV5055A4 USD 0.87; VPG 0.1 Ω 0.1 % foil shunt USD 13.05, due 12-Oct |
| AMF-304 | Faulhaber 2224 (DigiKey 2224.11000 USD 122.60; RS 2224U012SR ratings) |
| AMF-305, 306 | Pololu DRV8874 carrier USD 11.94; maxon ESCON Module 24/2 EUR 97.68 (NRND) |
| AMF-307, 308 | AS5047P board USD 19.40 (IC discontinued at DigiKey, 14-bit); Mean Well GST60A12-P1J USD 19.40 |
| AMF-309, 310 | stock N52 magnets (supermagnete 5 × 5 × 3, EUR 0.35; K&J B333-N52, USD 0.56, Br 14,800 G) |
| AMF-311, 312, 313 | Goodfellow CuBe2 wire and 301 foil starting prices; Ponoko etching limits (±0.13 mm, 1 mm minimum feature) |
| AMF-314, 315, 316, 317, 318 | Epson V39 II USD 129.99; Mettler Toledo M1 weights USD 535.50; MR63-ZZ USD 4.38; Hakko FA400-04 USD 93.79; Panasonic HG-C1030 USD 439.60 |
| AMF-319, 320 | NGK C17200 SDS (exposure operations, limits, controls); OSHA beryllium limits |
| AMF-321, 322 | Rigol DHO804 USD 459.00; Siglent SDM3065X USD 857.00 |
| OPT-100, 101 | PMW3360 breakout EUR 29.90, out of stock; PMW3610 at JLCPCB ("Extended", no price or stock shown) |

These existing rows are re-used: AMF-02, 15, 18, 19, 20, 220–225, 231, 233, 234, 236–238, 251; OPT-61, 88–91; CON-21, CON-100.

**Pages that gave no price**, and so carry ASSUMPTION ranges:
- me-systeme.de (HTTP 403) and pm-instrumentation.com (price after login), for the K3D40;
- FUTEK (shows $0.00), for the LSB200;
- Moticont (specifications only);
- Thorlabs (script-rendered pages);
- Omega (HTTP 403);
- Arducam and its resellers (HTTP 403);
- Pimoroni (pre-order).

---

## 13. Open items

1. **Prices not seen.** The K3D40, LSB200, LVCM-013, LM13, Nano17, XYZ stages, OV9281, PAA5100JE, Si3N4 balls, lapped races, coil winding, precision etching and custom magnets are all ASSUMPTION ranges. A request for quotation in week 0 pins them. They make up 72–90 % of the low-end core cost of B1, B2 and B4 (§2).
2. **Supply risks.**
   - OPA548T and OPA549T are back-ordered (AMF-301).
   - The PMW3360 breakout is out of stock, the PAA5100JE is on pre-order, and the PMW3610 is not at the large distributors (OPT-100, OPT-90, OPT-101).
   - The AS5047P IC is discontinued at DigiKey, though its boards are in stock (AMF-307).
   - The shunts are due on 12 October (AMF-303).
3. **No CAD** exists for:
   - the EXP-J17 (c) counter-face fixture;
   - the fatigue shuttle;
   - the wire clamps;
   - the anchor test frame;
   - R10's latency step flexure;
   - the translation-coupon stator (its solids exist in the STEP files, but no drawing does);
   - the five-bar's cable routing, tensioner, pen lift and encoder mounts, which the pass's CAD leaves unresolved.
4. **Kt on 0.10 mm wires.** A strain gauge cannot be bonded on the wire. The plan proposes 10× scaled coupons, since Kt depends on the geometry. The lead should confirm the method, because AC-K21-04, AC-BB04-03 and AC-B25-01 need a measured Kt.
5. **The titanium flange as a raceway.** 2.6 GPa of Hertz stress on Ti-6Al-4V (CALCULATION) probably indents it. Hardened inserts may be needed in the pen (AC-BB05-03 tests this). The CAD also has no ball retainer.
6. **Protocol wording.** DEC-098 (proposed) changes EXP-B25's "about 60 h at 200 Hz" in bench_protocols.md, which EXP-K21 follows. If DEC-098 is accepted, the lead edits that text.
7. **Id format.** The ids EXP-BB01…BB09 and AC-BB0x-yy do not match `validation/check_criteria.py`, whose patterns expect one letter and two digits (`AC-[A-Z]\d\d-\d\d`, `EXP-[A-Z]\d\d`). The lead either widens the patterns or renumbers when these rows go into `validation/acceptance_criteria.csv`. The proposed criteria otherwise pass the checker's other rules: requirement ids exist, and the direction and status vocabularies are respected.
8. **Firmware and software.** DAQ-1's firmware has never been compiled for the Teensy. The five-bar controller firmware is not written. `rig/` lacks the helpers listed in §10.2: resampling onto one clock, PAGE and IMU time mapping, and five analysis functions, of which three are drafted in `pipeline_check.py`.
9. **Study N may change the candidates.** The coupon fixtures accept either candidate. Freeze the coil and race drawings when study N reports; the stock-magnet coupons do not depend on it.
10. **R10's step source.** EXP-T05 names R13's stage, which is not in this build, so a small step flexure is proposed instead (§7.2).
11. **Encoder resolution.** `wholepen/grounded.py` assumes 16-bit output encoders, while the build uses 14-bit (8 µm against 2 µm of endpoint quantisation, CALCULATION). EXP-BB06 decides whether that matters. A 16-bit encoder was not priced.
12. **C17200 wire.** Goodfellow's 0.10 mm size in an aged temper is not confirmed (the table loads dynamically). The wire's resistance coefficient, needed for AC-BB04-04, is not in the ledger and is calibrated on the coupon.
13. **Not in this build.** Rev K's head mock-up (EXP-K23: the SQL-RV-1.8 is for volume customers, AMF-15), Hall interference (EXP-T09), EXP-T08 (its keeper pull needs a sensor above about 11 N, such as R12's K3D40 ±50 N; its thermal steps), and EXP-J17 (a) and (b), which need a built nose or nib. They come next.
14. **Money.** Currency conversion uses an ASSUMED 1.05–1.25 USD/EUR. Shipping, tax, duty and labour are excluded.
15. **Printer.** The CORE One's firmware must run with the extruder parked and its heaters at 0, and must toggle a marker output from G-code. Neither has been checked (§4.4).

---

## 14. Proposed rows for the lead

### 14.1 Decisions (DEC-095…099)

The full text is in `results/benchbuild/proposed_decisions.csv`.

| Id | Decision (proposed) | Alternatives | Basis | Revisit if |
|---|---|---|---|---|
| DEC-095 | **The first bench build is DAQ-1 plus R9 (G1), ordered in week 1 with every long-lead item for the G2 coupons, the five-bar and R10.** G1 runs in weeks 1–4: EXP-T02's minimum ink force first (with dead weights if the voice coil is late), then EXP-T01. No coupon geometry is frozen before G1's F_c,min and side load are known. The first force-constant coupons use stock magnets, with predictions regenerated at the as-built size (§0.2); custom magnets are ordered only after AC-T07-02 passes | coupons or the five-bar first; a six-axis F/T sensor for G1; custom magnets now | report §9 order; DEC-058; DEC-072; this plan's lead times (AMF-301, quotes) | a K3D40 or LSB200 lead time over 6 weeks (then the low-cost G1 build of `docs/measurement_rig.md` §2.9 starts first) |
| DEC-096 | **DEC-072's choice is made by re-running the pass's duty screen (`python -m revk.improve`) with measured inputs.** The screen's `residual_N` bundles contact, balance and guide loads, and it models no gravity term (`revk/improve.py`, `matched_force_duty`). The inputs are: the residual lateral load at the carrier (EXP-J17 (c), 95th percentile over 35–75° and roll, plus the moving mass's weight across the axis, 29.5 mN at 35° by CALCULATION); the K_m map (EXP-T07); the guide drag at the chosen preload (EXP-K20, BB05); and the anchor stiffness (EXP-BB03). The 1.5 mm candidate is taken only if its re-run worst copper loss stays within the 0.15 W allocation and EXP-BB04 passes. **Provisional reading** (CALCULATION, interpolating the pass's own 20/40/80 mN points): 0.15 W is reached at about 34 mN for the 1.5 mm candidate and about 53 mN for the 1.059 mm candidate. The calculated loads at 35° sum to about 49–51 mN: gravity 29.5, face residual at the 95th percentile 11.2–13.1, guide drag 8.1 (`bench_calcs.json`, a conservative sum of magnitudes) | choose on the calculated 20 mN screen now; choose on EXP-T01's side load alone | `mechanics_study.json`; `bench_calcs.json`; DEC-072 | the duty screen misses the first nib's measured coil heat (EXP-J17 (b), T12) by more than 20 % |
| DEC-097 | **Beryllium-copper wire is bought already age-hardened, so no heat treatment is done in-house.** It is cut with shears or flush cutters only, and never abrasive-cut, ground, sanded, pickled or acid-cleaned. Joints are soldered under a bench fume absorber, or crimped; nothing is welded. Offcuts, broken coupons and wipes go into sealed, labelled bags. No food or drink at the bench; hands are washed | age-harden in-house; laser-weld clamps (as study B did for titanium); abrasive cut-off | NGK SDS §2.1 exposure operations (AMF-319); OSHA limits (AMF-320); AMF-18; DEC-063 | no supplier can deliver aged 0.10 mm wire (then a supplier with beryllium controls heat-treats it) |
| DEC-098 | **Wire fatigue coupons (EXP-K21, B25, BB04) are driven at no more than 0.2 × the first transverse mode measured on each coupon.** Failure is detected by 4-wire resistance in current-carrying wires: an open circuit or a step over 2 %. Several coupons run in parallel on one crank shuttle, and 43.2 M cycles take 3–8 days per batch | 200 Hz as the protocol suggests (about 60 h); resonance tracking only | CALCULATION: first modes about 336–373 Hz (34 mm) and 487–763 Hz (26.8 mm); at 200 Hz the clamp stress rises about 90 % (34 mm) and 12–33 % (26.8 mm) | two drive frequencies on one coupon lot give the same cycles to failure |
| DEC-099 | **The grounded five-bar is benched with a passive 24 mm dummy pen and spring hand simulants, never with a person's hand, until a safety gate like G-S is written for it.** The first build includes: a hardware current limit at rated current; the 0.4 N cap in software (at rated current the linkage can still push about 1.06 N at its worst pose, CALCULATION); a breakaway pen coupling releasing at 0.5–0.8 N as the physical backstop; guards; and a latching emergency stop. Accepted-word results are claimed only from its measured replay (EXP-BB06, BB07), not from the rigid model | attach the fine nib first; test with a hand on the pen | DEC-071; the pass's 0 of 20 against 200 and 500 N/m grips; `prototype_stages.md`'s G-S principle | EXP-BB06 and BB07 pass and a G-S-type gate exists |

### 14.2 Experiments (EXP-BB01…BB09)

Each is proposed only where no existing experiment covers the need. The full text is in `results/benchbuild/proposed_experiments.csv`.

| Id | Gate | Rig | Title | Why no existing experiment covers it |
|---|---|---|---|---|
| EXP-BB01 | all (order 0) | DAQ-1 | DAQ-1 bring-up and time-base qualification | `docs/measurement_rig.md` §1.3 lists the bring-up steps with no id or criteria |
| EXP-BB02 | G1 | R9 | Frame qualification: plate mode, motion quality, in-situ calibrations | DEC-058 names the tap test as its falsifier, but no criterion judges it |
| EXP-BB03 | G2 | R12 + balance | The axially soft wire anchor (the pass's floating anchor) | EXP-K21 measures preload on Rev K's diaphragm, not the anchor's stiffness |
| EXP-BB04 | G2 | fatigue shuttle + DAQ-1 | The reach candidate's eight 34 mm C17200 wires at the 1.7 mm stop | EXP-K21's criteria fix Rev K's 26.8 mm wires and stop |
| EXP-BB05 | G2 | R12 stage + 10 g cell + laser lever | Ball-guide drag and tilt against preload, both guides | EXP-K20 tests one guide at one preload; the pass predicts 8.07 mN at 4 N, above K20's 5 mN line |
| EXP-BB06 | none yet | five-bar + K3D40 + camera | Five-bar qualification: kinematics, force, stiffness, force cap | no experiment tests the five-bar |
| EXP-BB07 | none yet | five-bar + passive pen + R3 | Accepted-word replay on paper against spring hands | the grounded results are SIM only |
| EXP-BB08 | sensing build gate | R10 + camera | Page anchoring through lift and occlusion | EXP-T04 judges the lift cut-off and dropouts, not absolute re-anchoring |
| EXP-BB09 | sensing and contact | R9 | Contact-channel delay, false contacts and lift timing | AC-B05-10 judges axial-force noise, not the contact decision's delay |

### 14.3 Criteria (33 rows)

The rows use the columns of `validation/acceptance_criteria.csv` and are in `results/benchbuild/proposed_criteria.csv`, with the full metric and basis text.

| Id | Req. | What | Line | Status |
|---|---|---|---|---|
| AC-BB01-01 | — | CRC errors and missing frames, 10 min at 8 kSPS | both met (0; 0) | derived |
| AC-BB01-02 | — | ADC noise, inputs shorted, gain 128, 4 kSPS | ≤ 2.4 µV RMS (2 × MFR 1.20 µV) | hypothesis |
| AC-BB01-03 | — | sync-pulse clock fit, largest residual | ≤ 50 µs | derived |
| AC-BB01-04 | — | encoder loop-back at 0.5 M counts/s | = 0 counts lost | hypothesis |
| AC-BB01-05 | — | current step 10–90 % and DC error | both met (≤ 2 ms; ≤ 1 % FS) | hypothesis |
| AC-BB02-01 | — | plate stack first mode (tap test) | ≥ 100 Hz | derived |
| AC-BB02-02 | — | steady-window speed within ±20 % | ≥ 95 % | hypothesis |
| AC-BB02-03 | — | plate calibration residual | ≤ 0.2 % FS | hypothesis |
| AC-BB02-04 | — | guide stiffness | within 17.9–33.3 N/m | hypothesis |
| AC-BB03-01 | — | anchor beam stiffness against 4 E w t³/L³ with measured t, w | within 0.85–1.15 | hypothesis |
| AC-BB03-02 | — | anchor with its interconnect | within 80–120 N/m | derived |
| AC-BB03-03 | REQ-BNIB-007 | assembly tension on the eight wires | ≤ 5 mN | derived |
| AC-BB04-01 | REQ-RVK-004 | lead resistance (two wires in parallel) | ≤ 0.3 Ω | requirement |
| AC-BB04-02 | REQ-BNIB-007 | cycles at the 1.7 mm stop with 0.1 A per wire | no failure in 43.2 M | derived |
| AC-BB04-03 | REQ-BNIB-007 | Goodman factor with measured Kt and tension | ≥ 1.5 | requirement |
| AC-BB04-04 | — | wire rise above its clamps at 0.16 A against the model's 45 K | within 0.75–1.25 | hypothesis |
| AC-BB04-05 | — | fatigue drive ÷ measured first mode (validity; also for K21, B25) | ≤ 0.2 | derived |
| AC-BB05-01 | — | reach guide drag at 4 N and the 35° couple | within 5.6–10.5 mN | hypothesis |
| AC-BB05-02 | REQ-RVK-003 | at the lowest preload with tilt ≤ 0.2 mrad, the drag | both met (tilt ≤ 0.2 mrad; drag ≤ 5 mN) | derived |
| AC-BB05-03 | — | marks on a bare Ti flange after drops | none | hypothesis |
| AC-BB06-01 | — | endpoint from encoders against camera truth (held-out poses) | ≤ 50 µm RMS | hypothesis |
| AC-BB06-02 | — | continuous force, lowest over directions and poses | ≥ 0.40 N | derived |
| AC-BB06-03 | — | stiffness at the pen holder | ≥ 4 N/mm | hypothesis |
| AC-BB06-04 | — | force cap and breakaway release (guarded) | both met (≤ 0.4 N; release 0.5–0.8 N) | derived |
| AC-BB07-01 | — | suffixes meeting the grounded gate, no spring hand | ≥ 18 of 20 | hypothesis |
| AC-BB07-02 | — | ink after refusal, 200 and 500 N/m springs | ≤ 0.5 mm | hypothesis |
| AC-BB07-03 | — | acceleration and jerk of every suffix | reported | derived |
| AC-BB08-01 | — | silent recoveries of the absolute anchor in ≥ 100 outages | = 0 | derived |
| AC-BB08-02 | REQ-RVJ-C05 | absolute error after re-anchoring, 95th percentile | ≤ 0.1 mm | derived |
| AC-BB08-03 | — | lost motion per outage | reported | derived |
| AC-BB09-01 | REQ-CTRL-003 | contact-decision delay against plate truth, 99th percentile | ≤ 5 ms | derived |
| AC-BB09-02 | — | false contact or lift decisions per minute | ≤ 0.1 | hypothesis |
| AC-BB09-03 | — | lift command to ink stop (R9 voice-coil lift) | ≤ 50 ms | hypothesis |

---

## 15. Files and how to run

```bash
python3 results/benchbuild/tools/build_tables.py     # BOMs, cost and schedule, map, proposed rows, evidence rows, templates (< 1 s)
python3 results/benchbuild/tools/bench_calcs.py      # CALCULATION: wire modes, anchor foil, selection thresholds, loads, five-bar bounds, R9 force reach (< 5 s)
python3 results/benchbuild/tools/pipeline_check.py   # SIM: synthetic data through the file formats and rig/ analyses (about 3 s)
python3 -m rig.selftest --no-write                   # 49 of 49 (SIM)
python3 -m pytest rig/tests -q -p no:cacheprovider   # 30 passed
```

All three scripts use `rig/`, `s2r/` and `wholepen/` read-only. They write only into `results/benchbuild/`, plus a temporary directory outside the repository.

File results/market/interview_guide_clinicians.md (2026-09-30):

# Interview guide B: occupational therapists, Parkinson's nurses and related clinicians (EXP-U03)

**Purpose.** Learn how clinicians meet writing problems in ET, PD and other tremor today, what they recommend, how they measure writing, who pays for equipment, and what evidence would make them recommend or buy a new tool (a measuring pen, a tablet app, a therapy kit, a desk surface or an active pen).

**Who.** 12–16 clinicians (saturation guidance, LITERATURE, HAP-164): occupational therapists (adult neurology, community equipment, paediatric for guide C), Parkinson's disease nurse specialists, movement-disorder neurologists or trial investigators, and speech and language therapists (for the dictation question). Mix NHS and private practice, and at least two people who run or recruit to clinical trials.

**Recruitment.** Professional networks and charities' professional channels (see `recruitment_and_ethics.md`). If clinicians are approached as NHS staff at NHS sites for a research study, HRA and HCRW Approval may apply (PDT-119); check with the sponsor's research office before contact.

**Length.** 40–45 minutes. No patient-identifiable information is collected; ask for anonymised examples only.

---

## 1. Opening script

"We are researching everyday writing difficulties in tremor and Parkinson's, and how clinicians support them. We are not selling anything today. Please do not share anything that could identify a patient. You can skip any question."

## 2. Caseload (5 min)

1. Roughly how many people with ET, PD or other tremor do you see in a typical month? How many raise writing?
2. Which writing problems come up most (tremor, small writing, slowness, fatigue, signing)? Which matter most to patients?
3. At what point do patients usually raise writing: early, when it affects work, when a document must be signed?

## 3. How writing is assessed now (8 min)

1. What do you use to assess writing? (Probe: a handwriting sample, spirals, TETRAS or Fahn-Tolosa-Marín items, the Bain-Findley ADL writing item, the MDS-UPDRS 2.7 patient item, the SOS test, timed copying; wearable monitors.)
2. How long does it take? What would you do differently if it took 5 minutes and gave numbers you trust?
3. Is writing measured in any trial you work on? Which endpoint? Who decides the endpoint?
4. What would a measurement tool need before you would use it: agreement with a clinical scale, test-retest reliability, time, cost, data security, regulatory marking?

## 4. What you recommend today (8 min)

For each option, ask what they recommend, for whom, and what happens in practice:
- weighted or thick pens and grips; clipboards and non-slip mats;
- practice, lined paper, cueing (for PD small writing);
- typing on phones or computers, and accessibility settings;
- dictation (probe: when does it fail? soft or unclear speech?);
- gloves, wrist weights, stabilising utensils;
- medicines or surgery (context only).

Then: "What do people come back and tell you did not work?"

## 5. Provision and who pays (7 min)

1. How do patients get equipment: NHS community equipment services, a charity, buying it themselves, their employer (Access to Work), insurance?
2. Is there a budget or a formulary for writing aids? Who signs it off?
3. Do you know of VAT relief on disability aids (HMRC Notice 701/7, PDT-117)? Do patients use it?
4. What price would stop you recommending a device that works? What price would need a funding application?

## 6. Evidence you would need (7 min)

Show the four concept cards (same wording as guide A, including the caveat that nothing is available or proven).

1. For each: who on your caseload, if anyone, would it suit? Who would it not suit?
2. What evidence would you need before recommending it? (Probe: comparison with a weighted pen and with typing or dictation; a blinded reading of the writing; safety; results for each condition separately.)
3. Any safety concerns? (Probe: magnets and implanted devices such as deep brain stimulators or pacemakers; heat; falls; fatigue.)
4. For the measuring pen: would you use it in clinic, at home between visits, or only in trials? How often?

## 7. Willingness to take part (3 min)

1. Would your service consider hosting a small study (EXP-U06 or EXP-U08)?
2. Could you share a study invitation with patients (with ethics approval)?

## 8. Close

Thank the person; explain the honorarium (if any) and its terms. Ask whether they may be recontacted.

---

## Coding frame

| Code family | Examples |
|---|---|
| Assessment | scale used, time, trust, gaps |
| Recommendation | aid, practice, typing, dictation, none |
| Failure reasons | fatigue, weight, speech, cognition, cost, adherence |
| Provision route | NHS equipment service, charity, self-pay, employer, insurer |
| Evidence bar | comparator, blinding, outcome, sample size |
| Safety flags | implants, heat, falls |
| Measuring use | clinic, home, trials, frequency, price anchor |

Feeds GNG-7 (clinician pull) and GNG-8 (measuring-pen demand) in `go_no_go_criteria.csv`.

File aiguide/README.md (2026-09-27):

# aiguide: AI prediction for physical guidance and digital autocorrect

**Evidence status.** Everything here is **SIMULATION** or **CALCULATION** on **synthetic** handwriting (glyph-font writers with synthetic tremor) and on a **public-domain text corpus**. No person was recorded and nothing was measured. The report is [`docs/ai_guidance.md`](../docs/ai_guidance.md); results are in [`results/ai/`](../results/ai/).

**The bound.** The nib stage can move the ink by at most its usable travel: ±0.30 mm in the pencil concept (`config/pencil.yaml` `stage.travel_nib`), ±0.55 mm in Rev A. Letters are 2–4 mm tall. The pen can only nudge strokes toward a predicted template; it cannot change one letter or word into another. Digital correction in the app is unbounded, and it never overwrites the original ink.

## Data

| Item | Source | Licence | Where |
|---|---|---|---|
| Text corpus | Tatoeba English sentences, CC0 subset: `https://downloads.tatoeba.org/exports/per_language/eng/eng_sentences_CC0.tsv.bz2` (retrieved 2026-09-27; 41 512 sentences, 3.3 M characters; SHA-256 `88741ad3…`) | CC0 1.0 (public-domain dedication; Tatoeba downloads page, "Sentences (CC0)") | `aiguide/data/tatoeba_eng_sentences_CC0.tsv.bz2` (snapshot; `corpus.ensure_corpus()` re-downloads only if it is missing) |
| Glyph font | single-line font of `app/penapp/synth.py` | repository code | imported, not copied |
| Writers, tremor | `aiguide/writer.py`, `stabpen.signals.tremor` | synthetic | generated per seed |

The rest of Tatoeba is CC BY 2.0 FR and is **not** used. The corpus is conversational example-sentence English (with a strong "Tom" bias and some opinionated quotations), not personal notes: every accuracy figure is a proxy for the user's own text.

## Modules

| Module | Role |
|---|---|
| `corpus.py` | Provenance, normalisation to the glyph alphabet (a–z, 0–9, `.,:-/'`, space), deterministic 80/10/10 split by hashed sentence id |
| `lm.py` | `CharKN`: interpolated modified Kneser–Ney character 7-gram, integer-coded n-grams counted with numpy (checked against a brute-force reference in the tests). `WordKN`: word bigram KN. `TextPredictor`: mixture, temperature calibration, `glyph_ahead(text, d)` (the d-th next *written* glyph), word prediction and completion |
| `adapter.py` | `TextPredictorProtocol`, the local `NgramAdapter`, `LLMPredictorSpec` (on-phone and cloud large-model adapter: specification only), `LatencyBudget` |
| `glyphs.py` | Font access and geometry helpers |
| `writer.py` | Synthetic writers: style, writer-specific allographs, per-instance variability, minimum-jerk timing, micrographia |
| `style.py` | Online style estimation: per-letter affine fit (ridge prior for degenerate glyphs, 10 ICP iterations), robust aggregation, baseline, spacing, speed, the user's own exemplars |
| `template.py` | Letter templates in the user's style (own exemplars, else font), app placement or pen anchoring at touchdown, stage-rate template tracks |
| `stroke_predict.py` | On-device stroke continuation: hold, constant velocity / acceleration (FIR), constant turn rate (circumcircle), 2×64 MLP (torch); Cortex-M33 MAC budget |
| `metrics.py` | Per-letter path distance, DTW legibility proxy, size-normalised DTW template-matching recogniser, travel-limit time |
| `guidance.py` | Closed loop on the **unmodified** simulators, `model.run(..., tmpl=...)`: the pencil model P1 (`sim/pencil`, configuration `pencil_P1`) and M1 (`sim/pensim`; `revA`, `pencil_like`, `pencil_0.3N` for comparison). Channel mapping, splice emulation of per-letter authority, static ink offset (M1 formula; P1 measured on the same writing without tremor), P1 writing-only scoring (touchdown and lift tails excluded), metrics |
| `icd_template.py` | Proposed ICD record 0x06 (template segment): reference encoder/decoder, framing through `penapp.logfmt`, bandwidth |
| `run_*.py` | One script per study (below) |

The app-side part of B3 is [`app/penapp/autocorrect.py`](../app/penapp/autocorrect.py) (noisy-channel correction stored as a derived `recognition` layer that keeps every span's stroke links, plus optional re-rendering in the writer's style); its tests are `app/tests/test_autocorrect.py`.

## Run

From the repository root, Python 3.11 with `requirements.txt` (torch CPU only for B1.3). Each script writes JSON through `stabpen.provenance` (git revision, parameter digest, seeds, command) and figures stamped with their evidence status.

| Study | Command | Output | Runtime here |
|---|---|---|---|
| B1.1 text predictor | `python3 -m aiguide.run_text` | `text_predictor.json`, `fig_text_calibration.png` | ~2.5 min (+2 min first build of the cached model in `aiguide/build/`) |
| B1.2 style templates | `python3 -m aiguide.run_style` | `style_templates.json`, `fig_style_template_error.png`, `fig_style_example.png` | ~5 min |
| B1.3 stroke continuation | `python3 -m aiguide.run_stroke` | `stroke_prediction.json`, `fig_stroke_prediction.png` | ~0.5 min |
| B2 closed-loop guidance (P1 and M1) | `python3 -m aiguide.run_guidance` (2 processes) | `guidance.json`, `viz_guided.json` (P1), `fig_guidance_*.png`, `fig_micrographia.png` | ~6 min |
| B3 autocorrect | `python3 -m aiguide.run_autocorrect` | `autocorrect.json`, `fig_autocorrect.png`, `autocorrect_rerender.svg` | ~1 min |
| B4 deployment | `python3 -m aiguide.run_deploy` | `deployment.json`, `fig_lead_time.png` | ~10 s |
| all | `bash aiguide/run_all.sh` | all of the above, then the tests | ~16 min (+2 min on the first run) |

Tests: `python3 -m pytest -q -p no:cacheprovider aiguide/tests` (32 tests, about 6 s) and `python3 -m pytest -q app/tests` (147 tests including the 10 of `test_autocorrect.py`, about 9 s).

Caches (git-ignored through `build/`): `aiguide/build/pred_o7_*.pkl` (trained predictor) and `aiguide/build/numba_cache/` (numba cache of the M1 and P1 simulator cores, kept out of `sim/`, which other jobs use). Nothing here writes into `sim/`, `stabpen/`, `config/`, `ml/`, `firmware/` or existing `app/` files.

## Conventions

- Seeds are fixed in every script and recorded in the result metadata. Writers are seeded by index; the simulator's sensor noise by writer; tremor by writer and frequency.
- Path distances are to the *ideal-pen ink path*: the intended path plus the static ink offset from the housing datum, because the guided core servoes the housing datum and a constant offset of all writing does not affect legibility. M1: the axial-slide formula `guidance.nib_offset`. P1: measured on the same writing without tremor, neutral mode (`guidance.ink_offset`, 4–7 µm).
- P1 draws a tail at every touchdown and lift: the unloaded refill protrudes up to 1.34 mm beyond its working point, so the ball stays on the paper while the refill travels and writes about 0.87 mm along the pen azimuth. P1 results are given for all ink and for the writing only (`guidance.writing_only`: nib contact while the skid is on the paper).
- The guided core (the same code in M1 and P1) has binary confidence. Per-letter authority c = min(1, ĉ/c_full), zero below c_min, is emulated by segment-wise runs at quantised `Controller.g_assist` levels spliced at the pen-up gaps; the splice discontinuity is measured and a one-run (mean authority) cross-check is reported.

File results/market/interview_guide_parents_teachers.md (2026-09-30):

# Interview guide C: parents, teachers, SENCOs and school occupational therapists (EXP-U04)

**Purpose.** Learn how much handwriting children with writing difficulties (developmental coordination disorder, dysgraphia, dyslexia) must still do, what support they get, what fails, and who would buy a tablet app, a therapy kit or a writing aid.

**Who.** Adults only: 12–16 interviews (HAP-164) split across parents or carers, class teachers, special educational needs coordinators (SENCOs) and school or paediatric occupational therapists, in primary and secondary schools. Children are not interviewed in this study. Any later study that involves children needs verified permission from a responsible adult, an age check before other personal data, and the child's own chance to decline, including in school (MRS Code rules 16–22, PDT-119), plus the study's safeguarding checks.

**Length.** 30–40 minutes.

**Do not.** Collect the child's name, school or work samples. Ask for descriptions, not documents. Do not suggest that any product treats dyslexia (the project's rule, HAP-47).

---

## 1. Opening script

"We are researching how children with handwriting difficulties manage writing at school and at home. We are not selling anything, and we will not ask for your child's or pupils' names. You can skip any question."

## 2. The writing load (8 min)

1. In a normal school day, how much does the child (or a typical pupil you support) write by hand? Which lessons? Homework?
2. What happens in tests and exams? (Probe: extra time, a scribe, speech recognition, a word processor. In England the normal way of working in exams is handwriting unless an arrangement applies; HAP-153.)
3. Tell me about the last time writing went badly for the child. What happened?

## 3. Support today (8 min)

1. What support does the child get: occupational therapy, handwriting groups, pencil grips, sloped boards, lined paper, typing, apps?
2. How often and for how long? (Probe: effective programmes include at least 20 practice sessions; HAP-41.)
3. What helped? What did not? Why was anything stopped?
4. Has typing been offered instead? How did that go? Does the child still have to handwrite?

## 4. Technology at school and home (6 min)

1. Which devices does the child use: tablet, stylus, laptop, phone? Owned by school or family?
2. Any rules or worries about screen time, data or apps in school?
3. Who chooses and pays for apps or equipment: parents, the class, the school's SEN budget, the local authority, an OT service?

## 5. Concept reactions (8 min)

Show only the cards relevant to children, with the caveat "an idea being studied; not available; not proven":

- **Card B. A tablet app with a stylus** for letter-formation practice and measuring progress, used with the teacher or therapist.
- **Card C. A practice kit with the therapist**: short daily exercises with feedback on paper or tablet.
- **Card A (optional). A pen that steadies itself** (show only if the adult raises tremor or motor control).

For each:
1. Would this fit the child's day? When exactly?
2. What would make you stop using it after a week?
3. What would you need to see before paying or asking the school to pay (evidence, trial period, therapist recommendation)?
4. Price: what would feel like a bargain, expensive but acceptable, too expensive (per year for an app, one-off for a kit)?

## 6. Close

Ask whether the adult would answer a short follow-up survey (EXP-U04 survey) and whether their school or service might pilot an app (GNG-9). Explain any thank-you payment and its terms.

---

## Coding frame

| Code family | Examples |
|---|---|
| Writing load | daily minutes, subjects, homework, exams |
| Arrangements | extra time, scribe, word processor, speech recognition |
| Support | OT, groups, grips, boards, apps, typing |
| Failure reasons | boredom, stigma, time, no transfer to schoolwork |
| Buyer | parent, school SEN budget, local authority, OT service |
| Unmet job | a school writing task current support does not solve (feeds GNG-9) |

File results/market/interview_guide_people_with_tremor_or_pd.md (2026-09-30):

# Interview guide A: adults with essential tremor or Parkinson's (EXP-U02)

**Purpose.** Learn which writing jobs people still do, which they have given up, what they use instead, and what they would pay to get back. The interview is about the person's life, not about our product. The product concepts appear only in section 6.

**Who.** Adults (18+) with clinician-diagnosed essential tremor (ET) or Parkinson's (PD) who say writing is affected (screening survey item S7 ≥ 1). Plan 12–16 interviews per diagnosis. Empirical studies reach saturation within 9–17 interviews for homogeneous groups (LITERATURE, HAP-164). Stratify each diagnosis by age (under 65 / 65+) and by self-rated severity (S7 = 1–2 / 3–4). Include at least 3 left-handed people and at least 3 people of working age.

**Stop rule (set in advance).** After 12 interviews in a diagnosis group, stop when 3 interviews in a row add no new job code (ASSUMPTION).

**Length.** 45 minutes, 60 at most. Offer a break every 15 minutes. Offer two shorter sessions if the person tires.

**Mode.** In person, video or phone. Offer large print, extra time, a carer or family member present (the participant answers), and typed or chat answers for anyone whose speech is hard to hear.

**Do not.**
- Collect or photograph a real signature, a real form or a real cheque. If the person wants to show how they write, use a made-up name and a made-up sentence (pseudo-signature, as in `validation/human_study_plan.md` §10).
- Diagnose, rate severity out loud, or give medical advice. If the person is distressed or reports a new symptom, use the distress protocol at the end.
- Pitch, or say that the device works. Nothing has been built and nothing is proven.

---

## 0. Before the interview

- Check the signed consent form and the optional recording consent.
- Note the screening answers (diagnosis, age band, dominant hand, S7, devices owned) so you do not ask again.
- Have ready: the four concept cards (section 6), the price sheet (section 7), a pen, plain and lined paper.

## 1. Opening script (read as written)

"Thank you for talking with us. We are a research team studying how people manage everyday writing: things like lists, cards, forms and signatures, on paper or on screens. We are not selling anything today, and there are no right or wrong answers. The most useful thing you can tell us is what really happens, including the times you avoid writing or ask someone else. You can skip any question and stop at any time. Is it all right to start?"

## 2. Warm-up (5 min)

1. Tell me a little about a normal week for you. Where does writing or typing come into it?
2. When did you first notice that writing had become harder? What changed?

## 3. Last-time stories (15 min)

Ask for a specific recent occasion each time. Use "the last time", not "usually". Probe: what, where, sitting or standing, how long, who read it, how it went, what you did afterwards.

1. **Lists and notes.** Tell me about the last time you wrote a shopping list, a note or a reminder by hand.
2. **Signature.** Tell me about the last time you had to sign something on paper: a form, a delivery, a card, a bank or legal document, a postal vote.
   - Probe: did anyone question the signature? Did you have to sign again? Did someone sign for you?
3. **Forms.** Tell me about the last paper form you filled in: at a doctor, a bank, a council, a school.
4. **Cards and letters.** The last birthday or greetings card you wrote.
5. **Avoided or delegated.** Tell me about the last time you chose not to write something, or asked someone else to write or sign for you. What was it? How did that feel?
6. **Drawing, puzzles, hobbies.** Is there anything you used to write or draw for pleasure that you have stopped?

## 4. Jobs, importance and frequency (8 min)

For each task mentioned, fill the grid together (read the scale aloud):

| Task | How often in the last month (every day / few times a week / few times a month / less / never) | How important that it is on paper and in your hand (1–5) | How hard now (1 none – 5 cannot) | What you do instead | What happens if it goes wrong |
|---|---|---|---|---|---|
| | | | | | |

Then ask:
1. Which one of these would you most like to be able to do again, or do more easily? Why that one?
2. For that task, could it be typed, dictated or done by someone else? What stops you?

## 5. Alternatives already tried (8 min)

1. **Typing.** Tell me about the last time you typed a message or a note on a phone, tablet or computer. How did it go? Have you changed any settings (for example, touch settings, larger keys, filters)?
2. **Voice.** Have you tried speaking to your phone or computer to write? The last time you did: how well did it understand you (0–10)? Where would you not use it (public, noisy places, private things)?
3. **Aids.** Which of these have you tried: weighted or thick pens, grips, a pen on a clipboard, gloves or wrist weights, a stabilising spoon, anything else? For each: how long did you use it, what was good, what made you stop? Score 0–10.
4. **Timing and medicine.** Do you plan writing around the time of day or medicine? (Record, do not advise.)
5. **Help from others.** Who helps you write or sign? How do you feel about that?

## 6. Concept reactions (7 min)

Show the four cards one at a time, in a random order (rotate across interviews). Read the caveat on each card: "This is an idea being studied. It is not available and has not been shown to help anyone."

- **Card A. A pen that steadies itself.** A pen about the size of a thick marker that moves its tip slightly to cancel small shakes. It needs charging.
- **Card B. A tablet app with a stylus.** Writing and drawing on a tablet screen with a pen; the app can show your writing larger and neater on screen, give practice exercises, and measure changes over time.
- **Card C. A practice kit with your therapist.** Short daily writing exercises with feedback, set up with an occupational therapist or nurse.
- **Card D. A desk writing surface.** A board that sits on a table and helps guide or steady the pen while you write on normal paper.

For each card ask:
1. What, if anything, would you use this for? Which task from section 4?
2. What worries you about it? (Probe: size and weight, charging, looks, noise, setting up, cost, being seen using it.)
3. How much time would you accept to set it up before writing: seconds, a minute, longer?
4. Would you rather have this, a better ordinary pen, or better typing or voice? Why?

## 7. Price and who pays (5 min)

Only for the card the person ranked most useful. Do not give a price first.

Van Westendorp questions (write the four numbers down):
1. At what price would it be so cheap that you would doubt it works?
2. At what price would it be a bargain?
3. At what price would it start to feel expensive, but you would still consider it?
4. At what price would it be too expensive to consider?

Then:
5. Who would pay: you, your family, the NHS or insurer, your employer, a charity? Have you ever received equipment through any of these?
6. Would you want to try it at home for a month before paying?

## 8. Close (2 min)

1. Is there anything about writing that we did not ask but should have?
2. Would you like to hear about future research (a separate yes or no on the consent form)?
3. Thank the person. Explain the thank-you payment: who pays it, what it is, when it arrives and any condition (MRS Code rules 25–26, PDT-119). Do not offer the project's own products as a thank-you.

---

## Distress and safety protocol

- If the person becomes upset: pause, offer a break or to stop, and do not continue the topic unless they want to.
- If they describe a new or worsening symptom, a fall, or thoughts of self-harm: stop the interview, follow the study's safeguarding procedure, and suggest they contact their GP, specialist nurse or an emergency service as appropriate. Give the Parkinson's UK or tremor charity helpline details listed in the participant information sheet.
- Record the event in the study log. Do not record clinical details in the interview notes.

## Coding frame (for analysis)

| Code family | Examples |
|---|---|
| Job | list, note, signature (legal, delivery, card), form (health, bank, council, school), card or letter, cheque, puzzle, drawing, work document |
| Setting | seated at a table, standing, in public, at home |
| Pain | illegible, slow, tiring, embarrassing, rejected signature, needs a helper, avoided |
| Workaround | typing, dictation, helper signs or writes, pre-printed labels, avoiding the task, medicine timing |
| Aid history | tried, abandoned (reason), kept |
| Unserved job | a paper-bound task that typing, dictation and current aids do not solve (feeds GNG-2) |
| Adoption barrier | weight, charging, looks, setup time, cost, trust |
| Payer | self, family, NHS, insurer, employer (Access to Work), charity |

Two coders code the first four transcripts independently and agree the codebook before coding the rest.

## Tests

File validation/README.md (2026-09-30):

# Validation plan

**Status (2026-09-28): PROPOSED. No experiment or study has been executed, no participant enrolled, no bench record exists.** Everything in this directory is one of three things:

- a proposed procedure;
- a prediction copied from `results/` with its source;
- an acceptance criterion whose number states its origin: a requirement id, a literature evidence id, a simulation or calculation file, or "engineering judgement".

Executed results will live only in [`records/`](records/README.md).

## 1. Files

| File | Content |
|---|---|
| [`bench_protocols.md`](bench_protocols.md) | 174 bench and offline protocols: EXP-B01…B10, S01–S02, F01–F02, M02–M03, P01–P02, E01–E02, C01–C02, A01, A03, the pencil-class Q01–Q08, I01 and I04 from the inertial study (§35–§36; I04 is superseded for Rev H by I06, and by T16), the Rev H I05–I07 (§37–§39), the guidance board G01…G06 (§40), and the Rev J studies: heel drive EXP-D01…D07, D10, D12, D13 (§41), inertial end-cap EXP-K01, K02, K04, K06…K08 (§42), nose v2 and autowrite EXP-N01…N08 (§43), simulator v2 validation EXP-V01…V07 (§44), the control stack EXP-L01, L02, L04, L05 (§45) and the integrated layout EXP-J01…J07 with Rev J.1's EXP-J10…J14, J16, the wear part of J15 and the nib's static load J17 (§46), study M's measurement rigs R9–R14 with EXP-T01…T17 (§47), study R's real-data experiments EXP-R02, R04…R07 (§48), study S's EXP-S16, S19, S20 and S21 (§49), study W's EXP-W11, W13, W14, W15 and W17 (§50), study B's EXP-B25, B28, B30 and B31 (§51; its other experiments run inside EXP-J17 and the EXP-T experiments), study E's EXP-E10…E13 and E17 (§52; E14 runs in EXP-L04, E15 in EXP-T10 and E16 in EXP-W01, with people), study K's EXP-K20, K21, K23 and K25 (§53; K22 runs in EXP-T07, and K24 is with people) study F's EXP-E21, E22 and E23 (§54; study F ran E13 and E11 in simulation, and E20 is with people) study H's first bench build, EXP-BB01…BB09, with the builds B0–B4, their gates and weeks (§55), study N's balanced nib, EXP-NB01…NB09 (§56), study P's moving-paper platen, EXP-PL01…PL08 (§57; PL03 and part of PL05 have participants), and study X's re-baseline, EXP-X01…X09 (§58; offline except X09, on R10) (§0.11 holds the pencil conventions; the A03, Q, Rev H, Rev J, real-data, study S, study W, study B, study E, study K, study F, study H, study N, study P and study X sections are compact: purpose and gates, predictions, set-up, procedure, measurands, criteria, decision rule; §47 gives each rig experiment's rig and gate, what it measures, the decision it enables, its procedure in brief and a pointer to `docs/measurement_rig.md`). Each of the others gives purpose and gated decisions, hypotheses with predictions, equipment classes and required accuracy, setup, procedure, sample size, data format, analysis and metric definitions, acceptance criteria, what result changes which decision, and risks. §0 holds the shared conventions: pre-registration, synchronisation, metrology and decision rules, randomisation and blinding, sample-size rules, the metric definitions that mirror `docs/physics.md` §8 and `sim/pensim/evaluate.py`, and the shared rigs R1–R8 (R9–R14 are in §47). |
| [`human_study_plan.md`](human_study_plan.md) | EXP-H01…H06: tremor-at-nib census, form factor, skid feel, training with retention and transfer, perception thresholds, and the immediate-assistance crossover. §12: EXP-A02, guidance acceptance with people (pencil concept). §13–§14: EXP-I02 (rotational share of writing tremor) and EXP-I03 (passive nose and grip options). §15: the Rev H outcome studies EXP-W01…W05 (pen mass, with study E's EXP-E16 and Rev K's 66 g in W01; tremor stabiliser, Parkinson's cues and size assist, guided practice, spelling help for dyslexia) and EXP-G07 (the guidance board with people). §16–§18: the Rev J studies with people: heel drive EXP-D08, D09, D11 (guided writing, tremor, lead-through with relaxed hands), inertial end-cap EXP-K03, K05 (user crossover, cue perception) and nose v2 EXP-N09, N10 (autowrite with people, since DEC-050 a research mode with the C1S nose and since DEC-071 superseded, not run; delayed ink). §19: study L with people: EXP-L03 (ink lag; shares sessions with EXP-N10), L06 (text prediction in the app), L07 (style synthesis) and L08 (guidance that fades across sessions). §20: the integrated layout with people: EXP-J08 (ink visibility; superseded for Rev J.1 by J15), J09 (mass and balance; Rev K's 66 g too), J15 (the clear window; the Rev K front too) and J18 (the heel wheel on writing). §21: study R with people: EXP-R01 (patients' own writing and tremor at the pen tip, the recording part of EXP-H01) and R03 (a reading panel against the AI reader). §22: study S with people: EXP-S10 (letters read while people write, inside EXP-H01/R01 sessions), S11 (a dyslexic misspelling corpus), S12 (a tick while writing), S13 (the tick's detection), S14 (personal prediction, with EXP-L06), S15 (shape assist, conditional), S17 (word recognition on the pen's recordings) and S18 (suggestions at pauses against cues while writing). §23: study W with people: EXP-W10 (tremor at the ink while writing, with EXP-H01/R01), W12 (holding and writing with the collar) and W16 (the cost of writing only when in reach, on Rev K's B1 nib). §24: study K with people: EXP-K24 (whether writers' fingers touch the paper with Rev K's grip). §25: study F with people: EXP-E20 (whether people read the E13 inks as the AI reader does, inside EXP-R03's panel). §26: study U, users and market: EXP-U01…U05 (customer discovery), U06 (the no-device pilot), U07 (the full comparison, which extends EXP-H06's conditions; DEC-092), U08 (a measuring pen) and U09 (a practice tool). §27: study P with people: EXP-PL09 (who would use the platen), the people part of EXP-PL05 and EXP-PL03's participants (their protocols are in `bench_protocols.md` §57). The **immediate assistance vs lasting improvement** separation is central (§1). Also covers populations, randomisation, blinding, outcomes, step-by-step sample sizes, analysis plans, adverse events and stopping rules, and ethics, regulatory and data-protection notes. |
| [`acceptance_criteria.csv`](acceptance_criteria.csv) | **Source of truth** for all criteria: 755 rows, 227 experiments. Columns: `id, requirement_id, experiment_id, metric, threshold, direction, basis, status, decision_gated`. |
| [`prototype_stages.md`](prototype_stages.md) | Stages A (bench rig with commercial actuators), B (tethered Rev A pen), C (untethered pen), D (product-form candidates, DEC-008). Gates G-A, G-B, G-S (safety before any participant), G-C, G-D and the claim gates C-IA, C-LI, C-CAP, each defined by criterion ids. Also: what each stage may and may not claim, a mermaid dependency graph, and the mapping to the phases of `docs/plan.md`. |
| [`records/README.md`](records/README.md) | How executed records are stored: layout, naming, mandatory `record.yaml` metadata, write-once raw data with SHA-256 manifests, verdict files, retention, human-data rules. |
| [`check_criteria.py`](check_criteria.py) | Checks the CSV (unique ids, requirement ids exist in `docs/requirements.csv`, status and direction vocabulary, coverage) and regenerates the criteria tables embedded in the two protocol documents. Edit the CSV, then run `python3 validation/check_criteria.py`; add `--check` to only check. Experiment ids have one or two capital letters and two digits (EXP-B25, EXP-BB01); `--selftest` tests the checker's own rules on made-up rows, which every run also does first. |

## 2. Conventions

- **Experiment ids:**
  - EXP-Bnn: bench physics (B01…B10); B20…B32 are study B's balanced nib (DEC-050). B25, B28, B30 and B31 have their own protocols (`bench_protocols.md` §51), and B30 includes participants; the other nine run inside existing experiments: B20 in EXP-T02, B21 in T01, B22 as EXP-J17's part (c), B23 in T07 and T08, B24 in T09, B26 in T10, B27 in T13, B29 in T15 and B32 in T04;
  - EXP-Snn: sensing and capture (S01, S02); S10…S21 are study S's spelling help, text prediction and clearer handwriting (DEC-056, DEC-057). S10…S15, S17 and S18 are with people, and S10 records inside EXP-H01/R01 sessions;
  - EXP-Fnn: faults;
  - EXP-Mnn: mechanics. M01 is unused, because the brief's list starts at M02;
  - EXP-Pnn: power;
  - EXP-Enn: estimation (E01, E02); E10…E17 are study E's causal tracker on real data (DEC-060, DEC-061): E10…E13 and E17 have their own protocols (`bench_protocols.md` §52); E14 runs in EXP-L04, E15 in EXP-T10, and E16 in EXP-W01 with people. E20…E23 are study F's readable target (DEC-067…069): E21, E22 and E23 have their own protocols (`bench_protocols.md` §54), and E20 is with people, inside EXP-R03's panel (`human_study_plan.md` §25); study F also ran E13 and E11 in simulation;
  - EXP-Cnn: capture and recognition;
  - EXP-Ann: AI;
  - EXP-Qnn: pencil-class concept (Rev P0) components and stages;
  - EXP-Inn: inertial control and the Rev H nose (I02, I03 are human studies);
  - EXP-Gnn: the guidance board (G07 is a human study);
  - EXP-Wnn: Rev H handwriting outcomes, human studies (W01…W05); W10…W17 are study W's whole-pen shift (DEC-051…DEC-053). W10, W12 and W16 are with people; the G5 parts of W11 and W14 run in EXP-T16;
  - EXP-Dnn: the Rev J heel drive (DEC-037). D08, D09 and D11 are human studies;
  - EXP-Knn: the Rev J inertial end-cap (DEC-038). K03 and K05 are human studies; K04 and K08 include participants. K20…K25 are study K's Rev K layout (DEC-062…066): K20, K21, K23 and K25 have their own protocols (`bench_protocols.md` §53), K22 runs in EXP-T07, and K24 is with people (`human_study_plan.md` §24);
  - EXP-Nnn: the Rev J nose v2 and autowrite (DEC-036, DEC-039, DEC-041). N09 and N10 are human studies. Since DEC-050 the C1S nose is a bench research module, and autowrite a research mode with it; since DEC-071 in-pen autowrite of whole words is no executable claim, and N09 is superseded (not run);
  - EXP-Vnn: simulator v2 validation (DEC-040). V03 runs inside EXP-H01, and V04 and V07 with participants; V06 is offline on human-study data;
  - EXP-Lnn: the Rev J control stack and app AI (study L; DEC-042, DEC-043). L03, L06, L07 and L08 are human studies; L01, L02 and L04 replay EXP-H01 recordings; since DEC-073, L05 tests only a bounded learned residual after bench identification, as a research comparison;
  - EXP-Jnn: the Rev J integrated layout (DEC-044), Rev J.1 (DEC-045) and the whole-pen simulation's tests (J17, J18; DEC-046, DEC-048). J08, J09, J15 and J18 are human studies (J15 has a bench part, the window's wear); J15 supersedes J08 for Rev J.1; J17's part (c) is study B's EXP-B22 (DEC-050);
  - EXP-Tnn: study M's measurement rigs R9–R14 (DEC-058, DEC-059). EXP-T12 part A is EXP-J17, which keeps its id; EXP-T03 has no criteria of its own (EXP-B02's judge it). Nine proposed criteria are kept under existing ids (`bench_protocols.md` §47), so the AC-T numbers have gaps;
  - EXP-Rnn: study R's real recorded data (DEC-054, DEC-055). R01 and R03 are with people; R01 is the recording part of EXP-H01, in its sessions; R07 runs inside EXP-T04 and T05. The informal EXP-R01 of `docs/revH_concept.md` is now EXP-I05 (renamed by the lead);
  - EXP-Unn: study U's users and market (DEC-090…094), all with people (`human_study_plan.md` §26): U01…U05 customer discovery (a survey, interviews and honest waitlist pages), U06 the no-device pilot, U07 the full comparison (it extends EXP-H06's conditions, DEC-092), U08 a measuring pen and U09 a practice tool;
  - EXP-BBnn: study H's first bench build (DEC-095…099; `bench_protocols.md` §55): BB01 DAQ-1, BB02 R9's frame, BB03 the soft wire anchor, BB04 the reach candidate's wires, BB05 the ball guide's drag against preload, BB06 and BB07 the five-bar (bench only, DEC-099), BB08 the page's re-anchoring and BB09 the contact channel's timing. The two-letter prefix keeps them apart from study B's EXP-B20…B32; the checker accepts one or two letters (studies N and P brought EXP-NB and EXP-PL, below);
  - EXP-NBnn: study N's balanced nib (DEC-080…084; `bench_protocols.md` §56): NB01 the double-array coupon, NB02 the ball's writing drag, NB03 the floating anchor, NB04 the leads' fatigue with current, NB05 the guide's drag and unloading against preload, NB06 a weight trim, NB07 the thermal mock-up, NB08 the built nib's mass, modes and lead clearance, NB09 the severe-tremor duty and the worst-case screen;
  - EXP-PLnn: study P's moving-paper platen (DEC-085…089): PL01…PL08 on the bench (`bench_protocols.md` §57; PL03 and part of PL05 with participants) and PL09 with people (`human_study_plan.md` §27);
  - EXP-Xnn: study X's re-baseline (DEC-075…079; `bench_protocols.md` §58): X01 the causal sim2j card on a second seed, X02 the balanced nib's card with measured loads, X03 autowrite with a realistic page sensor (the C1S bench module only), X04 guidance, write-big loops and lead-through under causal sensing, X05 an anisotropic force-constant map in sim2, X06 the reach check with the nib's nonlinear loads in HW1, X07 study E11's per-user gates with the faults repaired (information only), X08 a fresh real-input test split and X09 the page model's loss behaviour on R10 (with EXP-R07); all offline except X09;
  - EXP-Hnn: human studies.

  The ids used in `docs/` for B01–B10, S01, S02, M02, M03, E01, E02, H01–H05 are kept, and so are the Rev J studies' ids (D01…D13, K01…K08, N01…N10, V01…V07, L01…L08, J01…J18), study M's (T01…T17), study R's (R01…R07), study S's (S10…S21; S01 and S02 were taken, so study S starts at S10), study W's (W10…W17; W01…W05 are the Rev H outcome studies), study B's (B20…B32: B25, B28, B30 and B31 as experiments, the other nine as the names of the parts they run in, `bench_protocols.md` §51), study E's (E10…E17: E10…E13 and E17 as experiments, E14…E16 as the names of the parts they run in, `bench_protocols.md` §52), study K's (K20…K25: K20, K21, K23 and K25 as experiments, K22 as the name of the part it runs in, and K24 with people, `bench_protocols.md` §53; K01…K08 were taken, so study K starts at K20) study F's (E20…E23: E21, E22 and E23 as experiments, and E20 with people, `bench_protocols.md` §54), study U's (U01…U09, all with people, `human_study_plan.md` §26) study H's (BB01…BB09, `bench_protocols.md` §55), study N's (NB01…NB09, `bench_protocols.md` §56), study P's (PL01…PL09: PL01…PL08 in `bench_protocols.md` §57, PL09 with people) and study X's (X01…X09, `bench_protocols.md` §58). EXP-H06 is the immediate-assistance crossover that `docs/features.md` calls "immediate-assistance crossover study".
- **Criterion ids:** `AC-<exp>-<nn>`, for example AC-B09-02 or AC-BB04-02, where `<exp>` is the experiment's one or two capital letters and two digits.
- **`status`:**

  | Status | Meaning | Rows |
  |---|---|---|
  | `requirement` | The threshold is copied from `docs/requirements.csv`; `requirement_id` is set | 297 |
  | `derived` | The threshold is computed from a requirement, literature value, simulation result or design rule (ICD, decision log), or chosen to protect another criterion (metrology qualification). The derivation is in `basis` | 135 |
  | `hypothesis` | A prediction or proposed pass line about the device or the world, often engineering judgement, that the experiment tests. Thresholds taken from twin experiments (`sim_to_real.md`) say in `basis` that they are proposed design values, not measurements | 323 |

- **`direction`:** `<=`, `>=`, `<`, `>`, `=`, `within` (inclusive interval) or `pass/fail` (a conformity check described in `metric`).
- **Decision rules:** simple acceptance when TUR ≥ 4, otherwise guarded acceptance. Safety criteria always use guarded acceptance (`bench_protocols.md` §0.5).
- **Predictions are indicative until frozen.** Result files carry mixed parameter versions (EM 0.2.0; mechanics, CAD and ML 0.4.1; simulation, trade, thermal and drive calculations 0.4.4). Before each experiment the predictions are regenerated with the as-built parameters and frozen (`bench_protocols.md` §0.2).
- **False correction** (tremor-free writing moved by the pen). In sim2 it is the rms distance between the ink with a controller on and the ink of the device-off pen with the same noise and seed, and every controller must stay within 25 µm (REQ-RVJ-C02, AC-L02-05). In the earlier HW1 studies on synthetic writers it was judged relative to the Rev H tracker (≤ Rev H + 2 µm, REQ-CTRL-010), because those writers carry about ten times the measured 8–12 Hz content (DEC-040). On real recordings the absolute 25 µm bound of AC-E01-09 applies, so AC-L01-02 uses it. REQ-RVH-006 (AC-I07-01) keeps a stricter 15 µm for the Rev H tracker on recorded writing. On real writing the clean writing must itself pass REQ-DATA-003's kinematics check (≤ 2.5 % of its pen-down velocity energy at 8–12 Hz), and DEC-055's line uses the same absolute 25 µm as the mean over the test writers, with no single writer above 50 µm (AC-R02-01; AC-R05-01 too). Study W's collar must keep tremor-free writing within 25 µm with it enabled (REQ-WP-007, AC-W15-01).
- **Simulation evidence (DEC-070, DEC-075, DEC-076).** Simulations use causal sensing by default: the nib's velocity from timestamped Hall samples, the delayed measured contact channel, the Rev J inner loop at 80 Hz, and page model v2 (dropouts kept as lost motion; the absolute anchor invalid until restored). Closed-loop results computed with the legacy settings (exact velocity, immediate true contact, a 400 Hz loop, page model v1) stand only as labelled optimistic bounds (DEC-075). Study X (DEC-075…079, `docs/rebaseline.md`) reran most of them: sim2j's cards, study B's nib in sim2, study K's servo check, study F's reach check and the DeltaPen-class rows of studies R, E and F. A row it reran quotes its number and says "rerun by study X", with the register id of `results/rebaseline/impact_register.csv`. A row it did not rerun (study W's runs, the heel wheel, the gated listening tracker, the TCN replay, study B's thermal, face and slim-stage runs, study E11's per-user gates and others) stays suspended as device evidence and names the register's reason. A rerun of a published result first reproduces it with the old settings and pairs its cases (DEC-076). Predictions are regenerated with causal sensing before they are frozen (`bench_protocols.md` §0.2).
- **Nib figures (DEC-080).** Every nib power, skin and battery figure states its force-constant convention and comes from study N's matched model: the weakest point over the usable disk × 0.7 as the headline, with the centre × 1.0 beside it, until EXP-NB01 (or EXP-T07 for Rev K's B1) measures the map (REQ-RVK-006, AC-NB01-05). A measured power or temperature carries no convention; the model re-run with the measured map is reported beside it.
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

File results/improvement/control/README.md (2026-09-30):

# Control improvement evidence, 30 September 2026

These artifacts contain software checks, analytic calculations and synthetic physical simulation. They contain no hardware measurements, patient handwriting, reader study or proof of useful physical autocorrect. The full account is in `docs/control_improvement_audit.md`.

The implemented simulation now estimates velocity causally from timestamped noisy Hall measurements, gates contact from delayed measurements, scores required and unwanted ink separately, and uses an 80 Hz inner-loop design selected before final cases. Replacing the old 400 Hz gains under matched causal sensing removes a substantial instability. Learned residual policies were actually trained twice and rejected by their prewritten rules.

| Study | Data status | Result and principal files |
|---|---|---|
| Initial corrected-reward PPO | Three seeds × 16,384 transitions; separate train/tune/test writer IDs; ideal derivative and true-contact inner loop | Selected policy failed fresh test: large-case ratio 1.004476. `rl_integrity_results.json`, `rl_adoption_decision.json`, `research_checkpoints/`, `legacy_source_snapshot/` |
| Causal Hall sensitivity | Frozen initial PPO on its already spent test set, old 400 Hz gains | Fails clean-writing and ink gates. Post-hoc sensitivity only. `hall_sensitivity_results.json`, `causal400_source_snapshot/` |
| Servo design/calibration | Independent linear uncertainty grid then nine nonlinear engineering cases; gain frozen before nonlinear runs | Selects 80 Hz; old causal 400 Hz locally unstable. Bench still had true-contact gating. `servo_design_frozen.json`, `servo_design_results.json` |
| Aborted final comparison | Eleven paired cases inspected before discovery of remaining contact truth in inner servo | Aborted for model defect; no gain retuning; wholly new IDs used after correction. `aborted_hall_only_final/` |
| Final causal controller comparison | 45 fresh paired cases; five synthetic writers; identical Hall/contact sensing and target | 328→103 um mean clean-path error; 8.223→1.596 W mean copper power; five cases have worse error. `causal_controller_results.json`, `causal_controller_comparison.png`, `final_controller_source_snapshot/` |
| Larger causal PPO | Three seeds × 65,536 transitions; final checkpoints only; separate writers | All fail tuning. Best large-case ratio 0.998077 versus required <=0.98. Planned test split unconsumed. `causal_ppo/results.json`, `causal_ppo/checkpoints/`, `causal_ppo/source_snapshot/` |
| Timestep refinement | Three previously inspected cases, 12.5/25/50 us steps; common fine target | Maximum observed coarse/fine path difference 32.518 um; no universal numerical error bound. `timestep_sensitivity.json` |

The final controller intervals contain 112.5 s total scored writing. Required ink lasts 64.7685 s and required lift 47.7315 s. Missing ink decreases from 18.2005 s to 1.4670 s (**28.10%→2.26% of required ink**). Unwanted ink increases from 0.5530 s to 0.7995 s (**1.16%→1.67% of required lift**). Worst new trajectory error is 2.181 mm and maximum modeled winding temperature is 65.68°C after a short interval. The revised controller is a more defensible simulation baseline, not a production or clinical result. Its gains have not been validated for the proposed balanced nib or grounded five-bar.

Both PPO studies together completed 245,760 transitions across six seeds. They use different plants and protocols and must not be pooled as one efficacy experiment. All failed seeds and checkpoints remain available. No learned policy was deployed into firmware.

## Reproduction

Use the pinned Python environment, set `PYTHONNOUSERSITE=1`, and use one numerical thread per process. The executed runtime is Python 3.12 on macOS arm64; the original repository also has historical Linux/Python 3.11 results. Exact library versions are saved in the protocols.

From the repository root:

```sh
PYTHONNOUSERSITE=1 python results/improvement/control/reproduce_frozen_rl.py --mode smoke
PYTHONNOUSERSITE=1 python results/improvement/control/reproduce_causal_ppo.py --mode smoke
```

These export the recorded Git base plus the appropriate verified source overlay into an ignored build directory. They do not replace the working checkout. Each script also supports `--mode prepare`, `--mode evaluate`, `--mode train`, and `--destination NEW_DIRECTORY`. Use a new destination for a fresh full training or evaluation run. Reusing an already populated destination permits the frozen experiment's documented checkpoint/case cache behavior.

Both smoke replays were actually executed: one matched baseline/policy case from each source bundle reproduced all six saved numeric fields exactly on the same host. This verifies those cases, not a complete independent repetition of training. The later bundle contains all 82 source files declared in its executed protocol. Its original 4 kHz recording-rate prose error is preserved in the snapshot; `causal_ppo/protocol_clarification_record_rate.json` records the actual 2 kHz rate, corrected during training before tuning results.

`summary.json` provides a compact machine-readable handover. `figure_metrics.json` records the denominators used by the figure. Original repository results outside `results/improvement/` remain historical and are not silently rewritten to reflect the new model.

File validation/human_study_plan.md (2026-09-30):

# Human study plan

**Status: PROPOSED. No participant has been enrolled, no ethics application has been submitted, and no human data exist in this repository (2026-09-27).** Every number below is a design assumption, a literature value (evidence id from `docs/evidence.csv`) or an acceptance criterion from [`acceptance_criteria.csv`](acceptance_criteria.csv). None is a result.

Bench protocols are in [`bench_protocols.md`](bench_protocols.md). Stage gates, including the safety gate **G-S** that any powered prototype must pass before it touches a participant, are in [`prototype_stages.md`](prototype_stages.md).

Contents:

- §1 The central distinction: immediate assistance vs lasting improvement
- §2 Study overview
- §3 Elements common to all studies
- §4–§9 Studies EXP-H01…H06
- §10 Ethics, regulatory and data-protection notes
- §11 Sample-size summary
- §12 EXP-A02: guidance acceptance with people (pencil concept). It follows §10–§11 so that existing references to those sections stay valid.
- §13 EXP-I02: rotational share of writing tremor (inside EXP-H01 sessions)
- §14 EXP-I03: passive nose and grip options on writers (extends EXP-H03)
- §15 Rev H outcome studies: EXP-W01…W05, and EXP-G07 (the guidance board with people); EXP-W01 also answers study E's EXP-E16 (an 84 g dummy against a 12 g pen, PD and ET) and adds a 66 g dummy of Rev K
- §16 Rev J heel drive with people (DEC-037): EXP-D08 (guided writing), EXP-D09 (tremor), EXP-D11 (lead-through and autowrite with relaxed hands)
- §17 Rev J inertial end-cap with people (DEC-038): EXP-K03 (user crossover), EXP-K05 (cue perception); since DEC-051 only if an end-cap returns to the product
- §18 Rev J nose v2 with people (DEC-036, DEC-039, DEC-049): EXP-N09 (autowrite of accepted text), EXP-N10 (delayed ink); since DEC-050 the C1S nose is a bench research module, and autowrite a research mode with it; since DEC-071 EXP-N09 is superseded and not run
- §19 Rev J AI and control with people (DEC-042, DEC-043): EXP-L03 (ink lag; shares sessions with EXP-N10), EXP-L06 (text prediction in the app), EXP-L07 (style synthesis), EXP-L08 (guidance that fades across sessions)
- §20 Rev J integrated layout with people (DEC-044, DEC-045, DEC-048): EXP-J08 (ink visibility; superseded for Rev J.1 by EXP-J15), EXP-J09 (mass and balance, with EXP-K03; Rev K's 66 g too), EXP-J15 (the clear window; the Rev K front too), EXP-J18 (the heel wheel on writing)
- §21 Real recorded data with people (study R; DEC-054, DEC-055): EXP-R01 (patients' own writing and tremor, the recording part of EXP-H01), EXP-R03 (a reading panel against the AI reader; it also reads study F's inks, EXP-E20 in §25)
- §22 Spelling help, text prediction and clearer handwriting with people (study S; DEC-056, DEC-057): EXP-S10 (letters read while writing, inside EXP-H01/R01 sessions), EXP-S11 (a dyslexic misspelling corpus), EXP-S12 (a tick while writing), EXP-S13 (the tick's detection), EXP-S14 (personal prediction, with EXP-L06), EXP-S15 (shape assist, conditional), EXP-S17 (word recognition on the pen's recordings), EXP-S18 (suggestions at pauses against cues while writing)
- §23 Shifting the whole pen with people (study W; DEC-051…DEC-053): EXP-W10 (tremor at the ink while writing, with EXP-H01/R01), EXP-W12 (holding and writing with the collar), EXP-W16 (the cost of writing only when in reach, on Rev K's B1 nib since DEC-050)
- §24 The Rev K grip with people (study K; DEC-062): EXP-K24 (do the writers' fingers touch the paper?)
- §25 The readable target with people (study F; DEC-067): EXP-E20 (do people read the E13 inks as the AI reader does? inside EXP-R03's panel)
- §26 Users and market (study U; DEC-090…094): EXP-U01…U05 (customer discovery: a survey; interviews with people with ET or PD, with clinicians, and with parents or teachers; honest waitlist pages), EXP-U06 (the no-device pilot), EXP-U07 (the full comparison, which extends EXP-H06's conditions), EXP-U08 (a measuring pen) and EXP-U09 (a practice tool)
- §27 The moving-paper platen with people (study P; DEC-085…089): EXP-PL09 (who would use the platen), the people part of EXP-PL05 and EXP-PL03's participants (their bench protocols are in `bench_protocols.md` §57)

---

## 1. Immediate assistance vs lasting improvement

The pen may help a person in two different ways. The evidence, endpoints and claims for each must never be mixed (REQ-VAL-002, COR-20, DEC-002).

| | **Immediate assistance (IA)** | **Lasting improvement (LI)** |
|---|---|---|
| Question | Is writing better **while the device acts**? | Is **unassisted** writing better after practising with the device, does it last, and does it transfer? |
| Device state when the outcome is measured | ON (ASSIST_KF, ASSIST_ML or GUIDED; `docs/icd.md` §6) compared with sham (NEUTRAL_HOLD) and OFF | **OFF**, or an ordinary pen, at every outcome test |
| Timing | Within a session, minutes | Baseline → end of practice → **delayed retention** (7 days for novices, 6 weeks for PD) → **transfer** (untrained material, dual task, ordinary pen) |
| Study | **EXP-H06** | **EXP-H04** |
| Primary outcome | Tremor in the **deposited ink** (free writing) or path distance to a template (guided tasks) with the device ON vs NEUTRAL | Unassisted shape error (novices) or unassisted letter size (PD micrographia) at delayed retention |
| Main risk | Distortion of intended strokes (REQ-CTRL-005); hidden dependence on the device | Error-removing assistance can **impair** unassisted retention and transfer (HAP-09; also HAP-02, HAP-04, HAP-06) |
| Claim allowed if the study succeeds | "While the pen was in use, [metric] in [population] was reduced by [effect, CI] compared with the same pen not correcting." | "After [dose] of practice with [training mode], unassisted [metric] in [population] was [effect, CI] better than control practice at [retention interval], and transferred to [tasks]." |
| Claim **not** allowed | Anything about writing without the device, or about learning | Anything about performance while the device is active |

### Rules that enforce the separation

- **R1.** Every endpoint in every statistical analysis plan (SAP) is labelled IA or LI. No composite endpoint mixes them.
- **R2.** The device mode during each outcome test is set by the study app from the randomisation code, logged (ICD event 0x0001 "mode change") and verified from the logs before analysis. A test done in the wrong mode is a protocol deviation, not data for the other endpoint.
- **R3.** EXP-H06 ends with an unassisted block to detect after-effects (for example reliance or a transient improvement). It is labelled **exploratory** and is never evidence of LI.
- **R4.** EXP-H04 records assisted performance during practice (acquisition), but reports it separately. **Acquisition gains are not evidence of learning** (HAP-04, HAP-06, HAP-09).
- **R5.** Claims are made per user group (REQ-USR-001) and per mechanism (DEC-002):
  - nib correction → action and essential tremor, within the amplitude limits of REQ-USR-002;
  - cueing, feedback and practice → Parkinson's micrographia. A ±0.5 mm stage cannot enlarge strokes (COR-10);
  - capture and notes → everyone.
- **R6.** Device modes map to claims:

  | Claim type | Device modes |
  |---|---|
  | IA | ASSIST_KF, ASSIST_ML, GUIDED, cue-on |
  | LI (training only) | TRAINING_FADE and the fading cue schedule |
  | Outcome tests | OFF or NEUTRAL_HOLD |

### What the current evidence predicts, and why the design hedges

The simulation (synthetic handwriting) finds that no causal estimator separates tremor from intended writing below about 9 Hz (COR-11; `docs/sim_report.md` §3.2). The frequency gate (DEC-009, default 7.5 Hz) therefore keeps free-writing cancellation off for lower frequencies.

Essential tremor in a clinic sample had a frequency of 5.79 ± 1.32 Hz (Elble 2000, screened in `docs/research/notes/PDT_pd_et_handwriting.md` §1.2). If that distribution holds for writing tremor at the nib, only about 10 % of ET patients have tremor above the gate (P(f ≥ 7.5 Hz) = 0.098 for a normal distribution).

Combined with the amplitude limit (about 50 % of ET within 2 mm p-p, PDT-12), **free-writing cancellation might address only about 5 % of ET patients** (if amplitude and frequency are independent), unless:

- EXP-H01 finds a different frequency distribution at the nib; or
- EXP-E01 finds better separation on real writing than the simulation predicts.

For that reason the immediate-assistance study (EXP-H06) has two pre-specified variants: free writing (H06-F) and guided tasks (H06-G). The choice is fixed at gate G-C, before enrolment, from EXP-E01, E02 and B09 results. Guided (known-path) assistance is the credible near-term use: in simulation it cuts the path distance on circles and spirals to 0.29–0.37 of neutral (`results/sim/guided_path_distance.json`).

---

## 2. Study overview
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

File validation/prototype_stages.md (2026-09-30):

# Prototype stages, gates and the order of experiments

**Status: PROPOSED PLAN. No stage has started; no gate has been passed (2026-09-27; §0 added 2026-09-29).**

- Gates are defined by acceptance-criterion ids from [`acceptance_criteria.csv`](acceptance_criteria.csv).
- Protocols are in [`bench_protocols.md`](bench_protocols.md) and [`human_study_plan.md`](human_study_plan.md).
- Decision ids (DEC-…) refer to `docs/decisions.md`.

## 0. Current order for Rev J (2026-09-29): the review's gates on study M's rigs

This section supersedes the Stage A equipment and critical path below. **The nib to build is a balanced nib** (DEC-050): gate G2 tests its coupons, G3 the one-axis nib and G4 the two-axis nib, at the candidate DEC-096 chooses at G2 (below). Since DEC-072 two fine-stage candidates go to the bench. **The reach candidate is now study N's balanced design** (DEC-083, `docs/nib_optimisation.md`: ±1.5 mm in the 24 mm body with two magnet arrays, 157 mm long), which replaces the pass's ±1.5 mm design; **the margin candidate is Rev K's B1** (±1.06 mm, `docs/balanced_nib.md`), laid out with study N's floating anchor. Under study N's matched model (DEC-080) the balanced design takes less power at more reach: 37.9 against 64.6 mW in typical writing and 0.107 against 0.17 W in the worst-case screen (CALC). So DEC-096's re-run is predicted to choose it. That reverses study H's provisional reading, which was made on the pass's own screen of the pass's 1.5 mm design (about 34 mN of residual load against about 49–51 mN calculated at 35°). For tremor the reach matters only at the severe class: no causal estimator yet uses more than ±1.0 mm on real tremor (DEC-060). Even with perfect knowledge, and with B1's own servo and moving mass, ±1.06 mm gains +1.6 words at the severe class against DEC-055's +2, while ±1.5 mm gains +3.2 (study X, DEC-078; SIM on real inputs). So a ±1.06 mm nib is a moderate-tremor nib. The C1S nose is built only as a bench research module (autowrite, EXP-N08/N09/S19, and EXP-J17's check of the static-load model). For the Rev J nib and earlier notes, the stage structure (bench → tethered pen → untethered pen → product form) and the principles stand. Sources: the independent review of 29 September 2026 and the lead's response (`docs/reviews/2026-09-29_review_response.md` §3–§4), study M's rigs (`docs/measurement_rig.md`, DEC-058, DEC-059) and `bench_protocols.md` §47. Nothing has been built.

| Order | Review gate | Rig (study M) | Experiments | What passing decides |
|---|---|---|---|---|
| 0 | all | DAQ-1: one 24-bit simultaneous DAQ, encoders, camera trigger, sync pulse | bring-up (`docs/measurement_rig.md` §1.3), judged as EXP-BB01 (study H) | every later rig shares one clock |
| 1 | **G1** contact and ink | R9 on a converted CoreXY printer: force plate under the paper plus an in-line axial cell (DEC-058) | EXP-T01, T02 (EXP-B01 re-specified, B08, Q02), T03 (B02, optional); **EXP-J17** (the nib's static side load and holding power at 35/50/75°); R9's frame qualification (EXP-BB02) and the contact channel's timing (EXP-BB09) | the lowest refill force that writes, the static side load the nib must carry, the friction map of the simulator; the balanced nib's design range (DEC-046, study B) |
| 2 | sensing build gate | R10 on R9's frame | EXP-T04, T05 (EXP-S01 with DEC-059's metric, EXP-J10 with its accumulated-drift rule); page re-anchoring through lifts (EXP-BB08); the page model's loss behaviour on paper (EXP-X09, DEC-079) | whether ordinary-paper sensing is good enough for guidance and autowrite (REQ-RVJ-C05); which die and optics |
| 3 | people, in parallel as soon as ethics allows | R11: tablet protocol (no build), then the recording pen | EXP-H01 (with T06), EXP-V07 | who the pen can help (tremor at the nib), the real axial/normal force split, the writer-model refit |
| 4 | **G2** actuator coupon | R12 coupon bench | EXP-T07–T09 (N01, J01, J14, B03); B1's wire coupons and drops (EXP-B25) and the IMU's tilt error for the face schedule (EXP-B28); Rev K's buildable coil in EXP-T07 (study K's EXP-K22), its ball thrust guide (EXP-K20) and its C17200 wires carrying the coil current (EXP-K21); the balanced candidate's coupons (study N): its force map (EXP-NB01, in place of EXP-T07's second coupon), its floating anchor (EXP-NB03), its leads carrying current (EXP-NB04, on DEC-098's shuttle) and its guide (EXP-NB05); its writing drag (EXP-NB02) runs on R9 with EXP-J17 (c)'s fixture. EXP-BB03…BB05 (the pass's superseded 1.5 mm design) are not built | the actuator's force map, magnetic pull and Hall interference before a nib is built; DEC-072's fine stage, through DEC-096's duty re-run; study N's build gate (below) |
| 5 | **G3** loaded one-axis nib, then **G4** complete two-axis nib | R13 loaded-nib rig (fixed bridge with a one-axis paper table) | G3: EXP-T10, T11, T12 part B (I05, B05, B09); G4: EXP-T13–T15 (N02–N06, J05, J13, B07); before the Rev K pen, the counter-face head mock-up on EXP-J17 (c)'s stage (EXP-K23) | correction bandwidth under contact; turns, roll, dropout and a 30-minute heat run |
| 6 | **G5** collar and tail | R14 grip simulant on R13's shaker | EXP-T16, T17 (K02, J16, I06; supersedes I04) | whether a moving collar or tail beats the same mass locked (≥ 10 %) |
| 7 | **G6** grounded guidance | heel bench and board rigs | EXP-D04…D08, EXP-G01…G07; EXP-J18 (people, after G-S) | whether any heel-wheel mode earns a place (it is retracted by default, DEC-048) |
| 8 | **G7** recognition and suggestions | offline, on recorded writing | EXP-L06, EXP-A03, study S's tests | spelling, completion and recognition on held-out people |
| 9 | **G8** user study | the pen that passed G1–G5, after G-S | `human_study_plan.md` | benefit to people (none is claimed before this) |
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

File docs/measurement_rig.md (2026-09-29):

# Measurement rigs for gates G1-G5 and page sensing (study M)

**Status: PROPOSED DESIGN, 2026-09-29. Nothing has been built or measured.** This document specifies the bench rigs that the independent review of 29 September 2026 asks for (§12 "Experiments that decide the design"; the lead's response §4). It provides the CAD, the acquisition firmware, the logger and every analysis as runnable code, tested on synthetic data only.

**Labels** (as the rest of the repository):
- **SIM**: synthetic data run through the rig analyses (`rig/synth.py`, partly through `s2r`'s instrument models). It checks the software, not a pen.
- **CALC**: a calculation (uncertainty budgets, force envelopes, sizing).
- **LIT (id)** / **MFR (id)**: a published or manufacturer statement with its ledger id (`docs/evidence.csv`, or the rows proposed in `results/rig/evidence_rows.csv`, only for sources opened in this study).
- **ASSUMPTION**: an input nobody has measured.
- **PROPOSED DESIGN**: a choice made here.
- **MEASURED**: nothing yet.
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

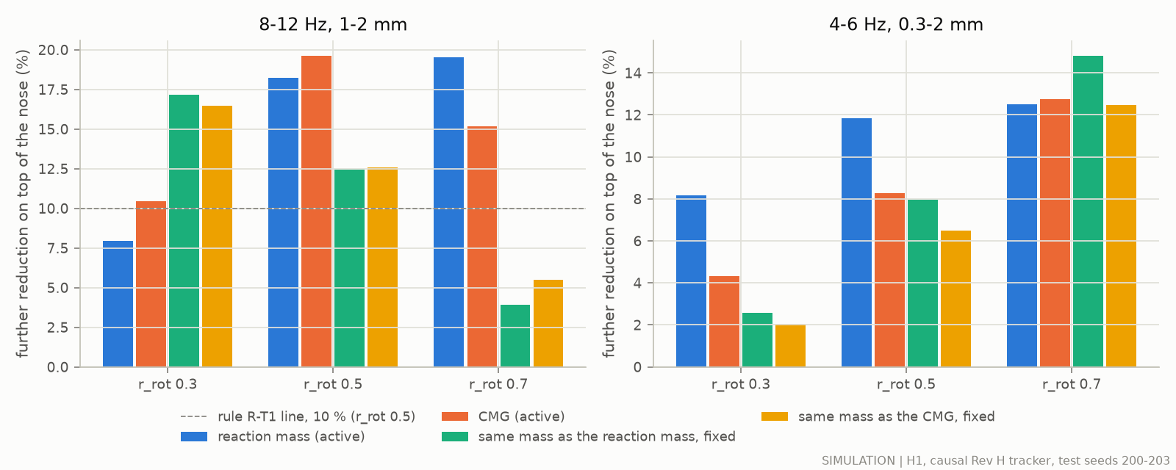
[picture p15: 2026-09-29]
viewer/figures/results__endcap__fig_ek_tremor.png

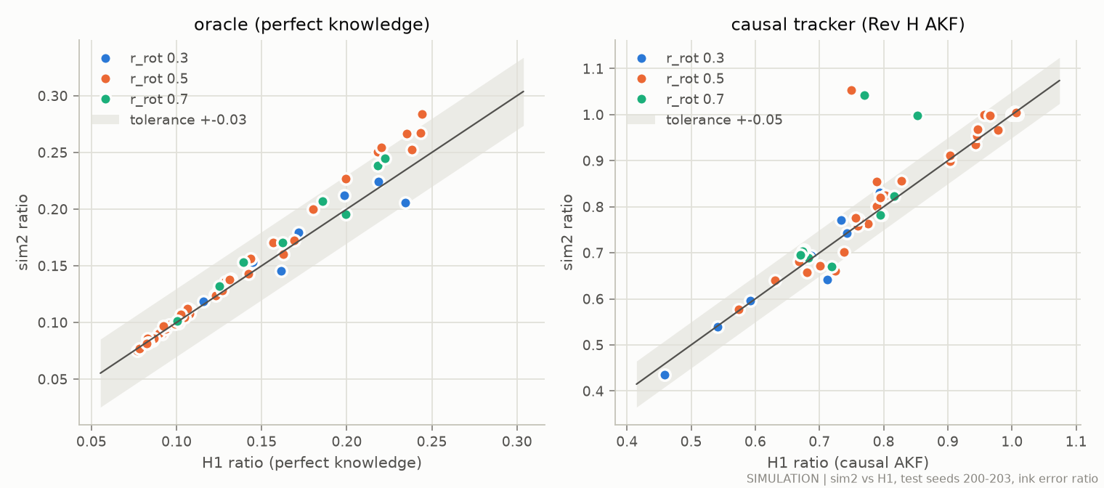
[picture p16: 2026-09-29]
viewer/figures/results__sim2__fig_sim2_h1check.png

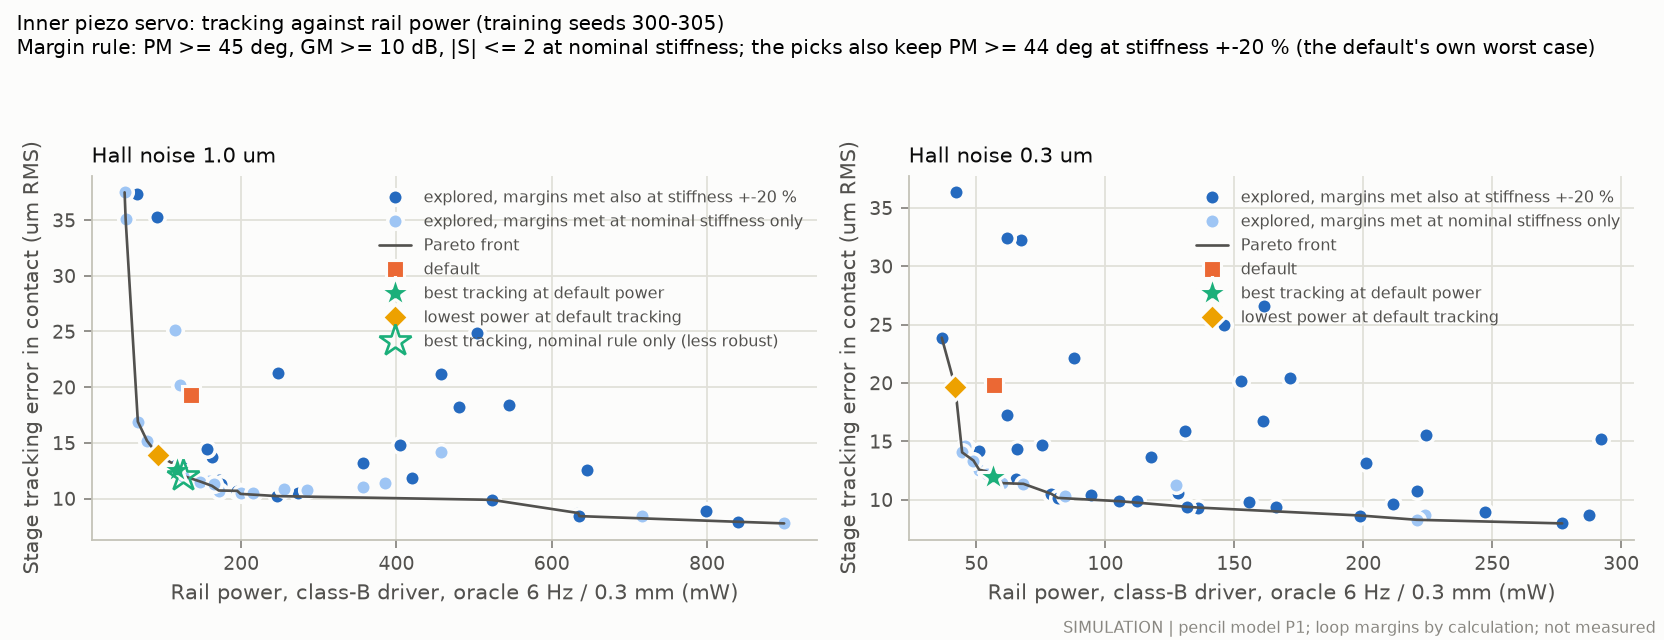
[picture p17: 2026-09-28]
viewer/figures/results__opt__fig_td_servo.png

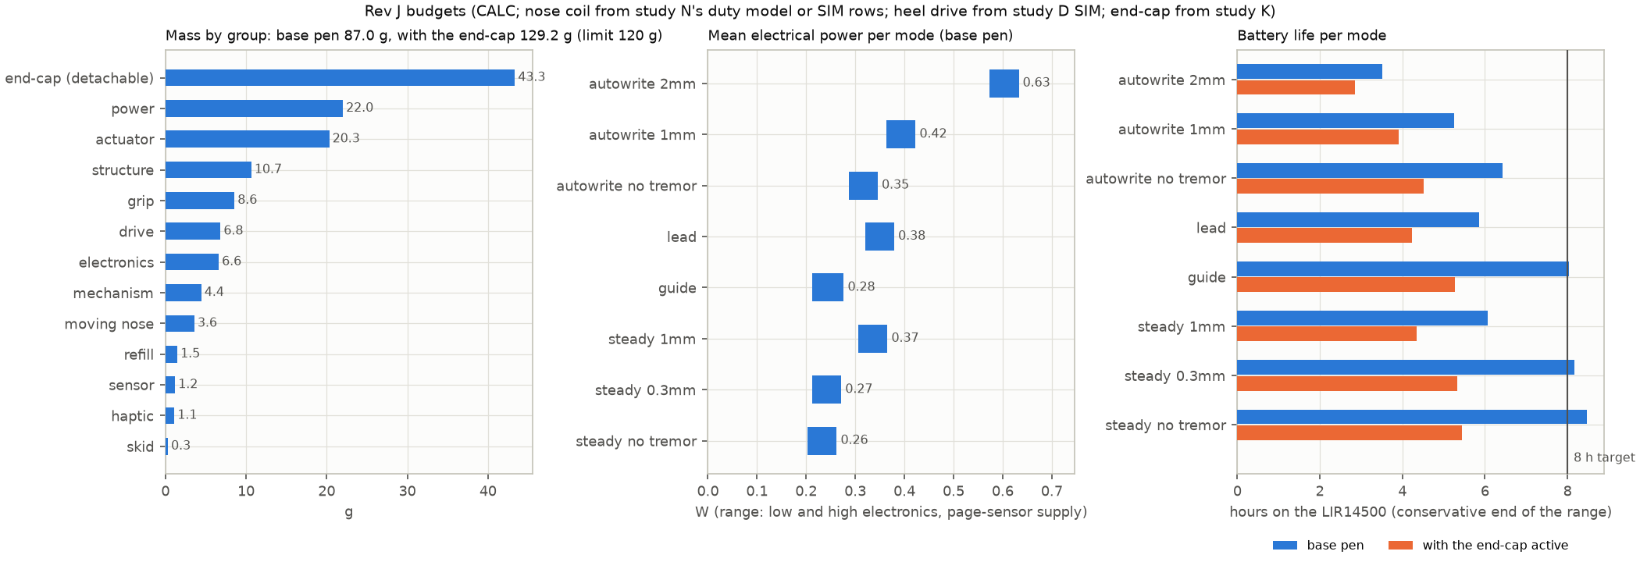
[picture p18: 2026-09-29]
viewer/figures/results__revJ__fig_revJ_budgets.png

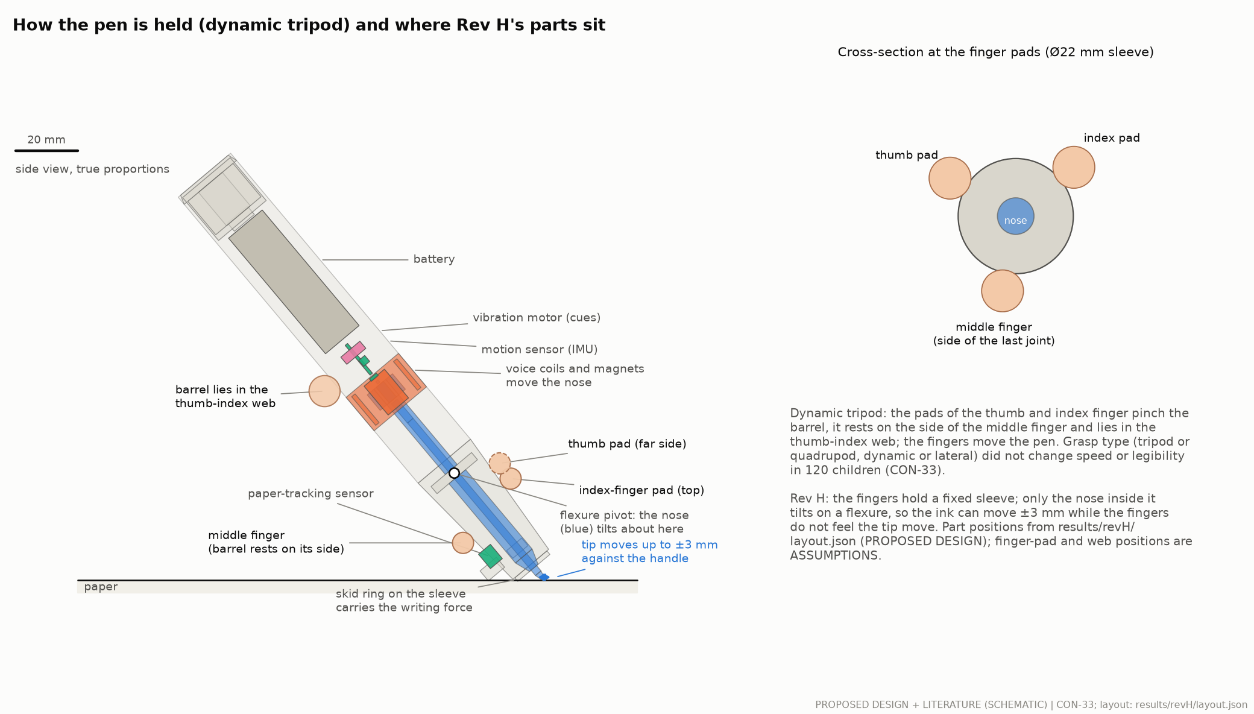
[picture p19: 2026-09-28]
viewer/figures/results__handwriting__fig_primer_grasp.png

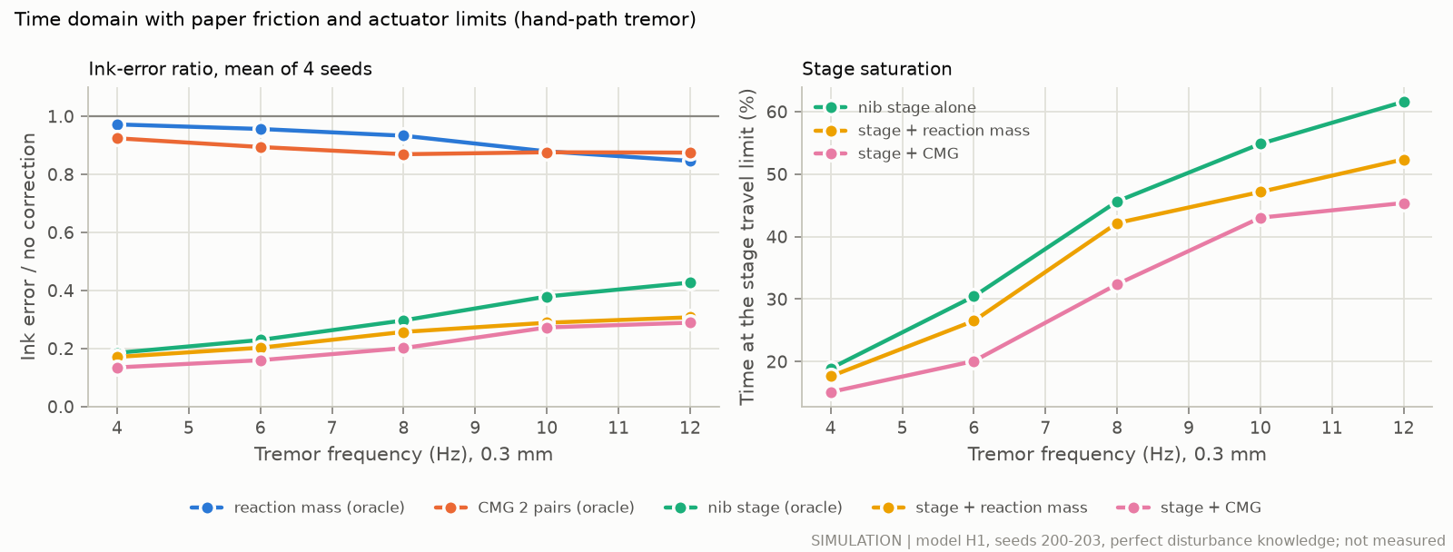
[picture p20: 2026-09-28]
viewer/figures/results__pencil__fig_inertial_timedomain.png

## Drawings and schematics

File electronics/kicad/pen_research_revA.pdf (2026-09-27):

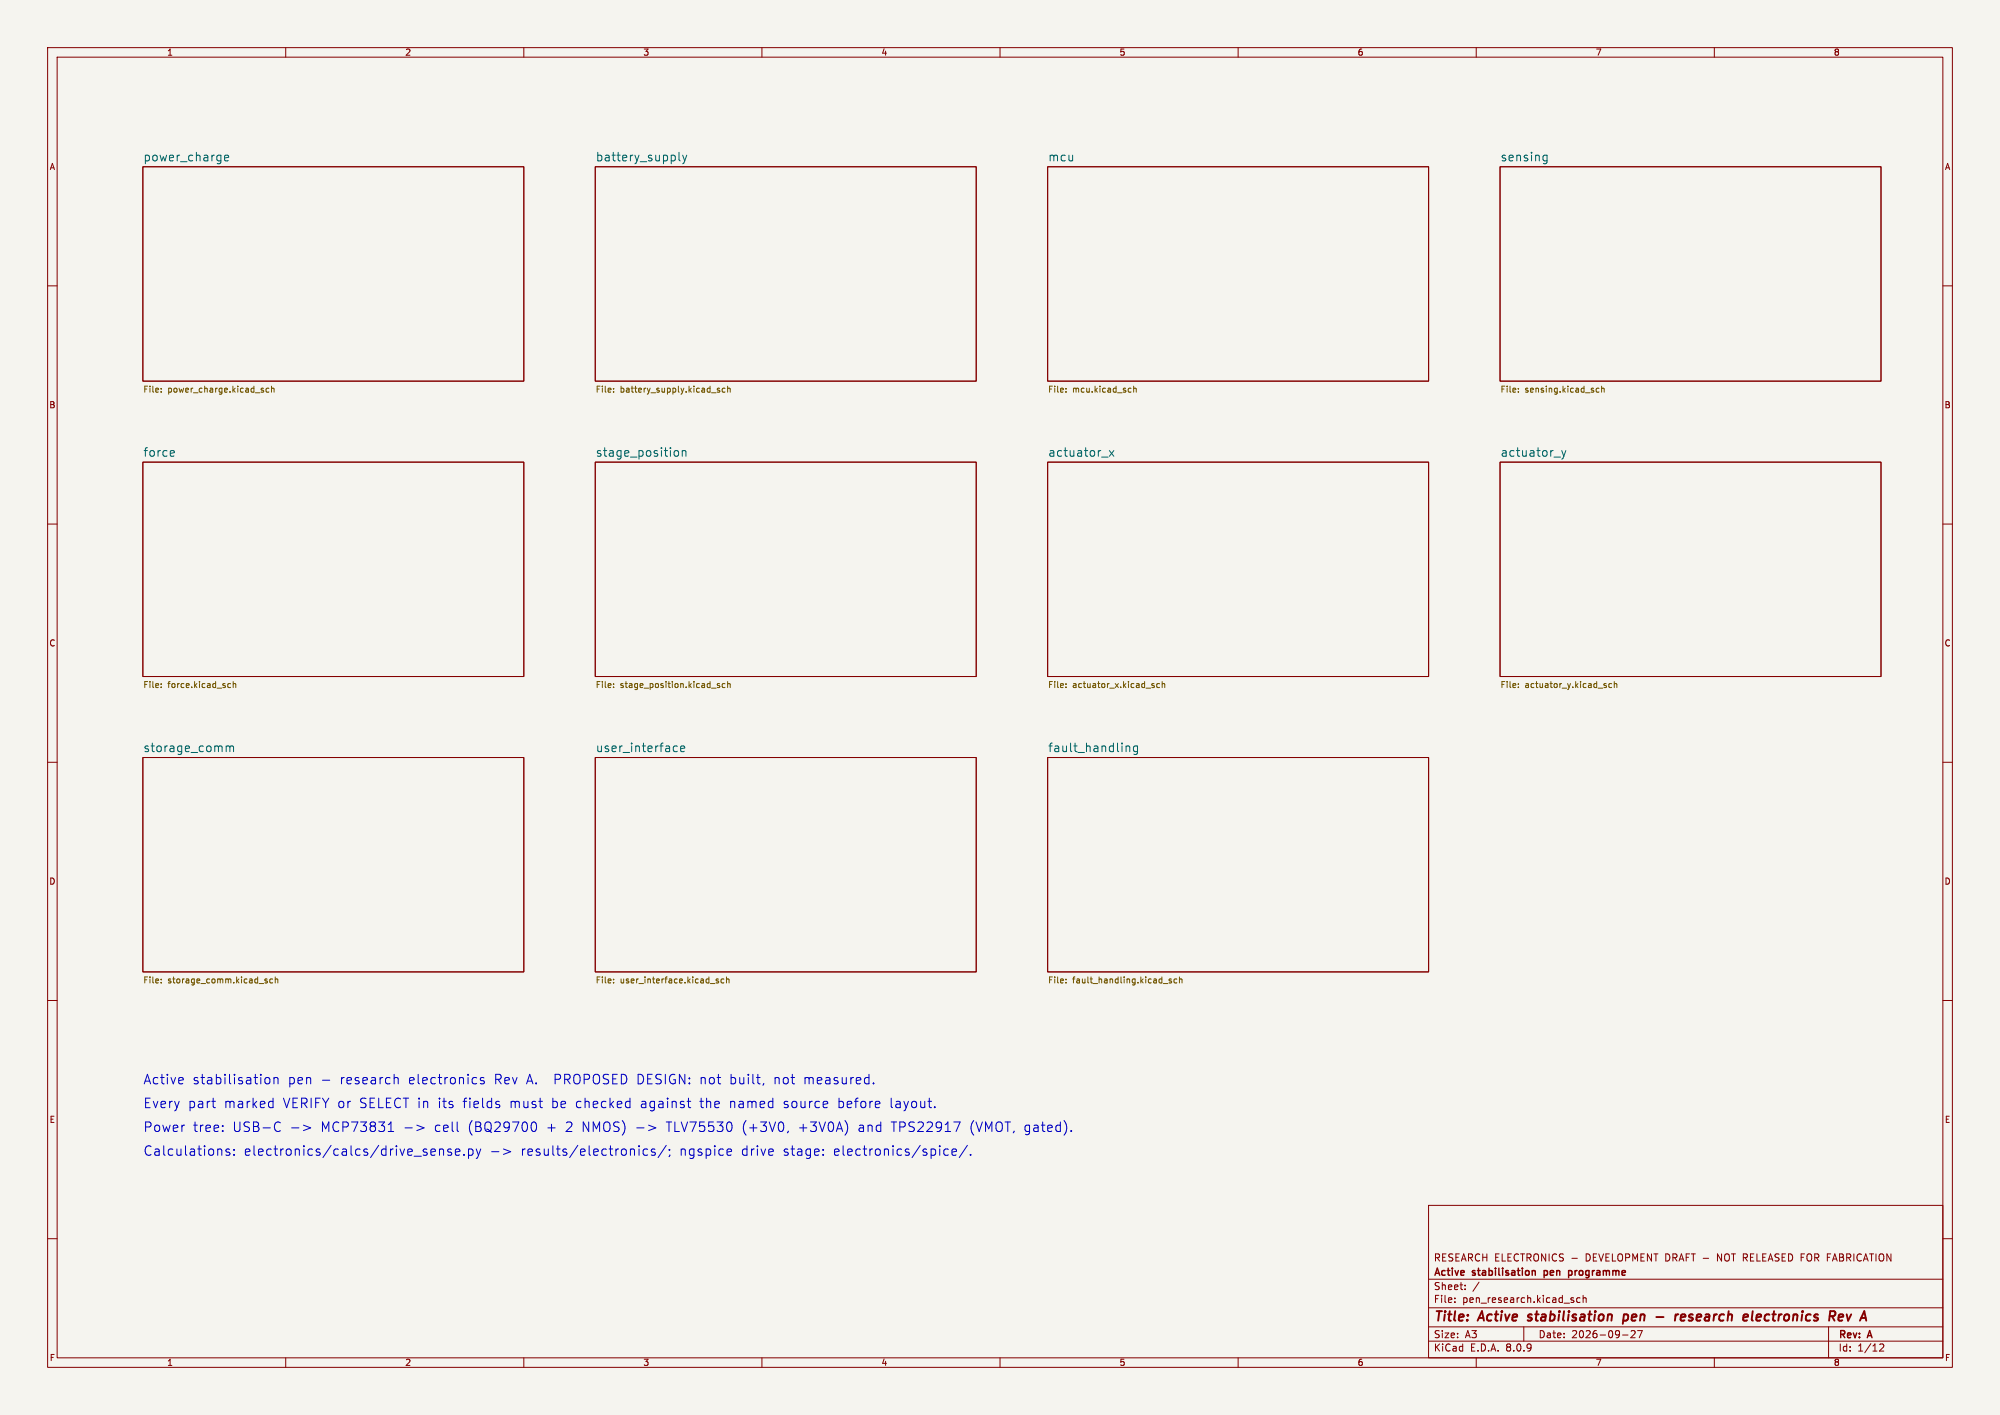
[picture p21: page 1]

Every part marked VERIFY or SELECT in its fields must be checked against the named source before layout.

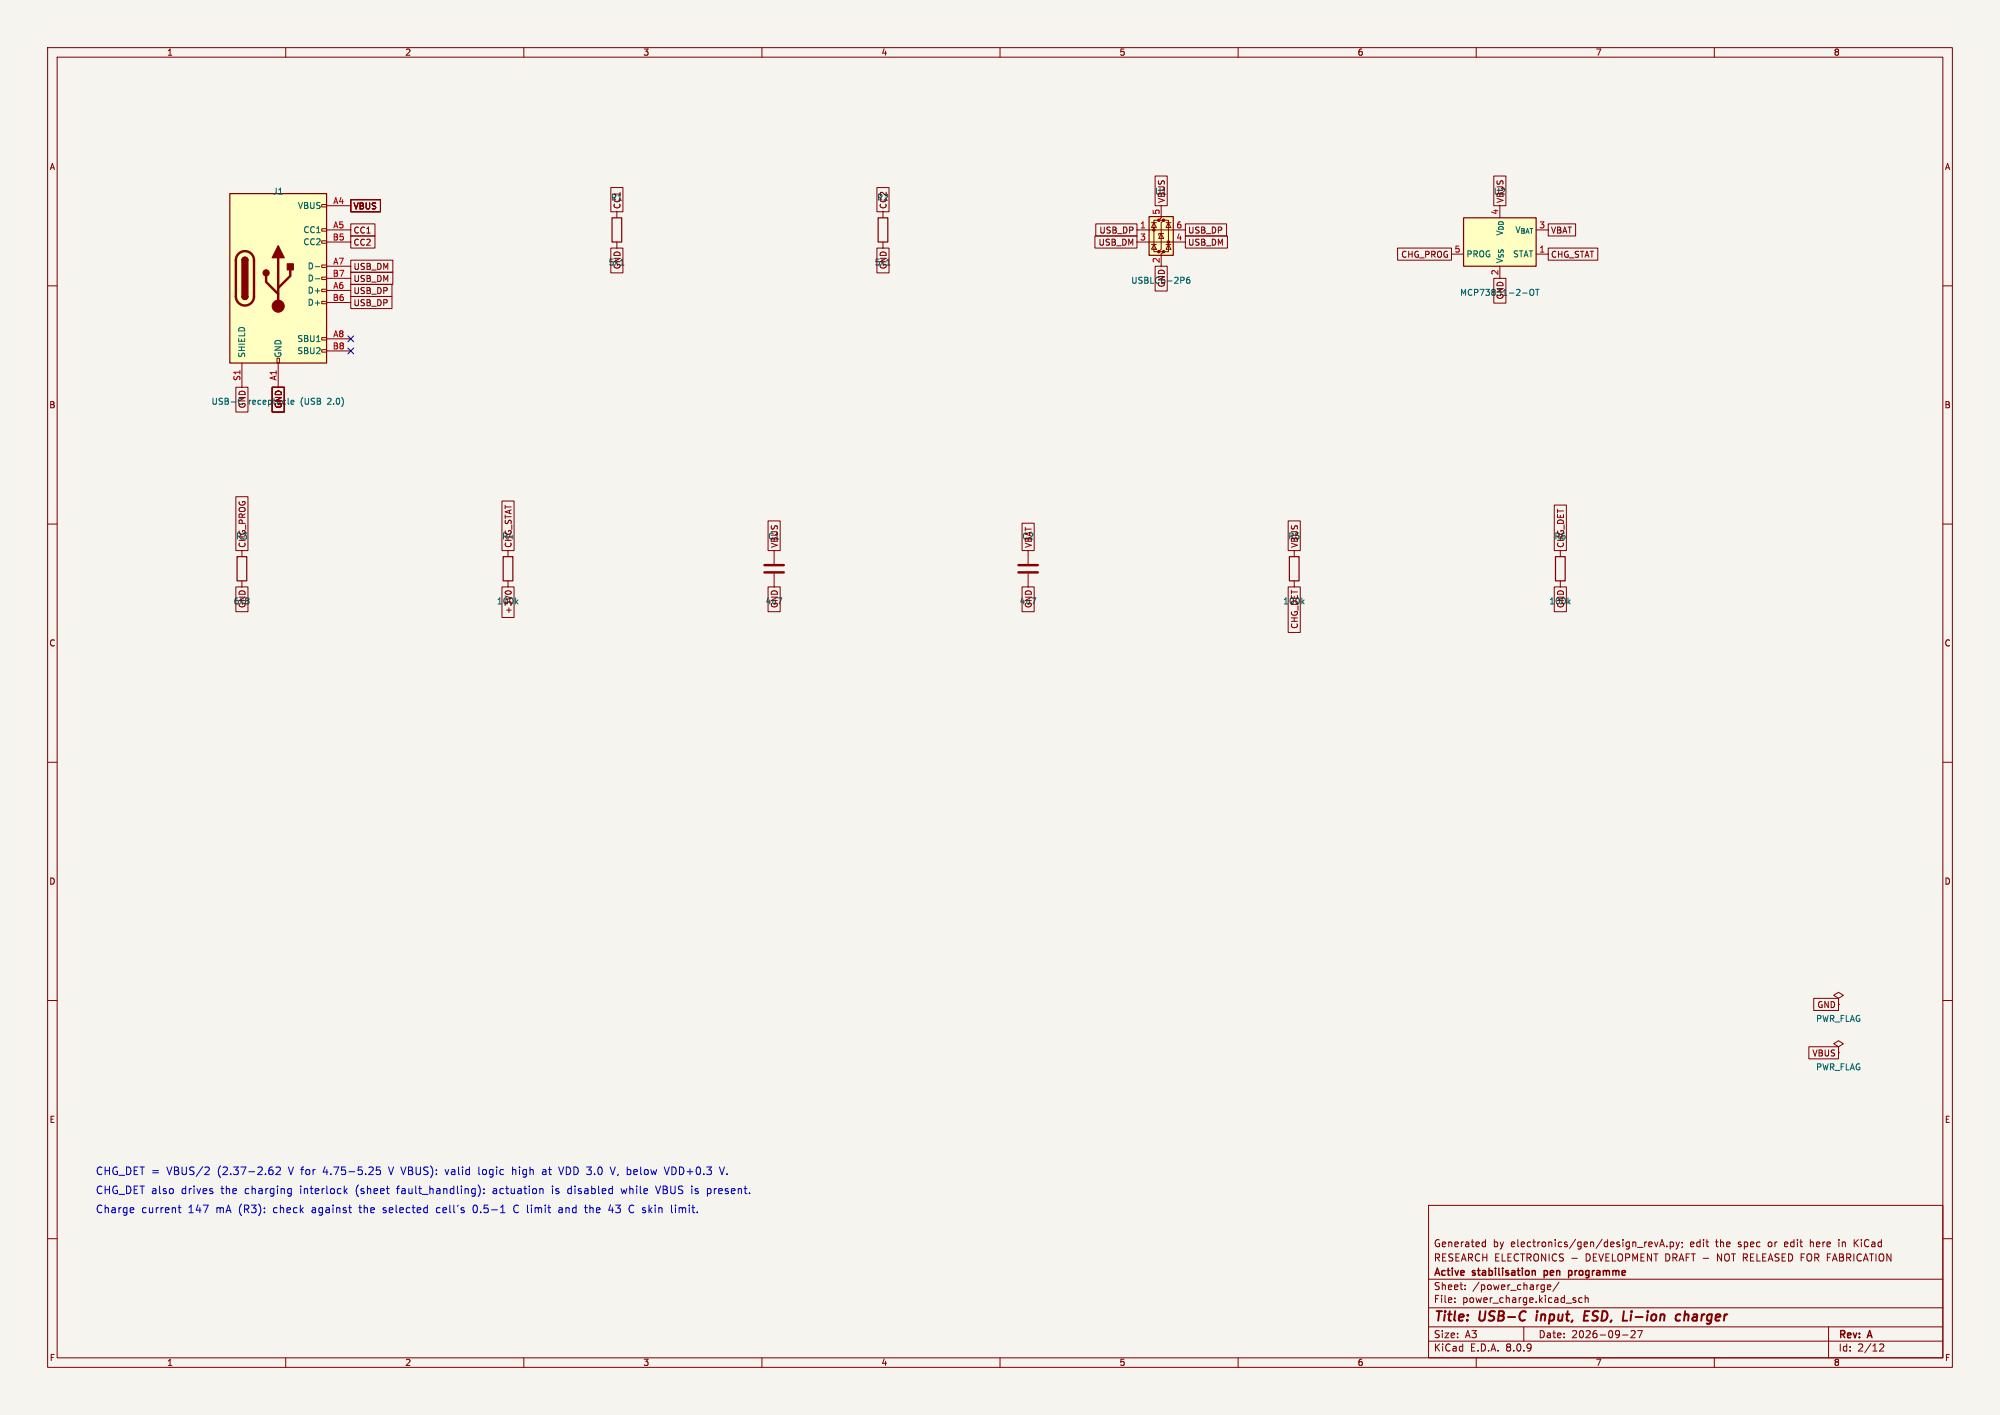
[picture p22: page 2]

VBUS GND

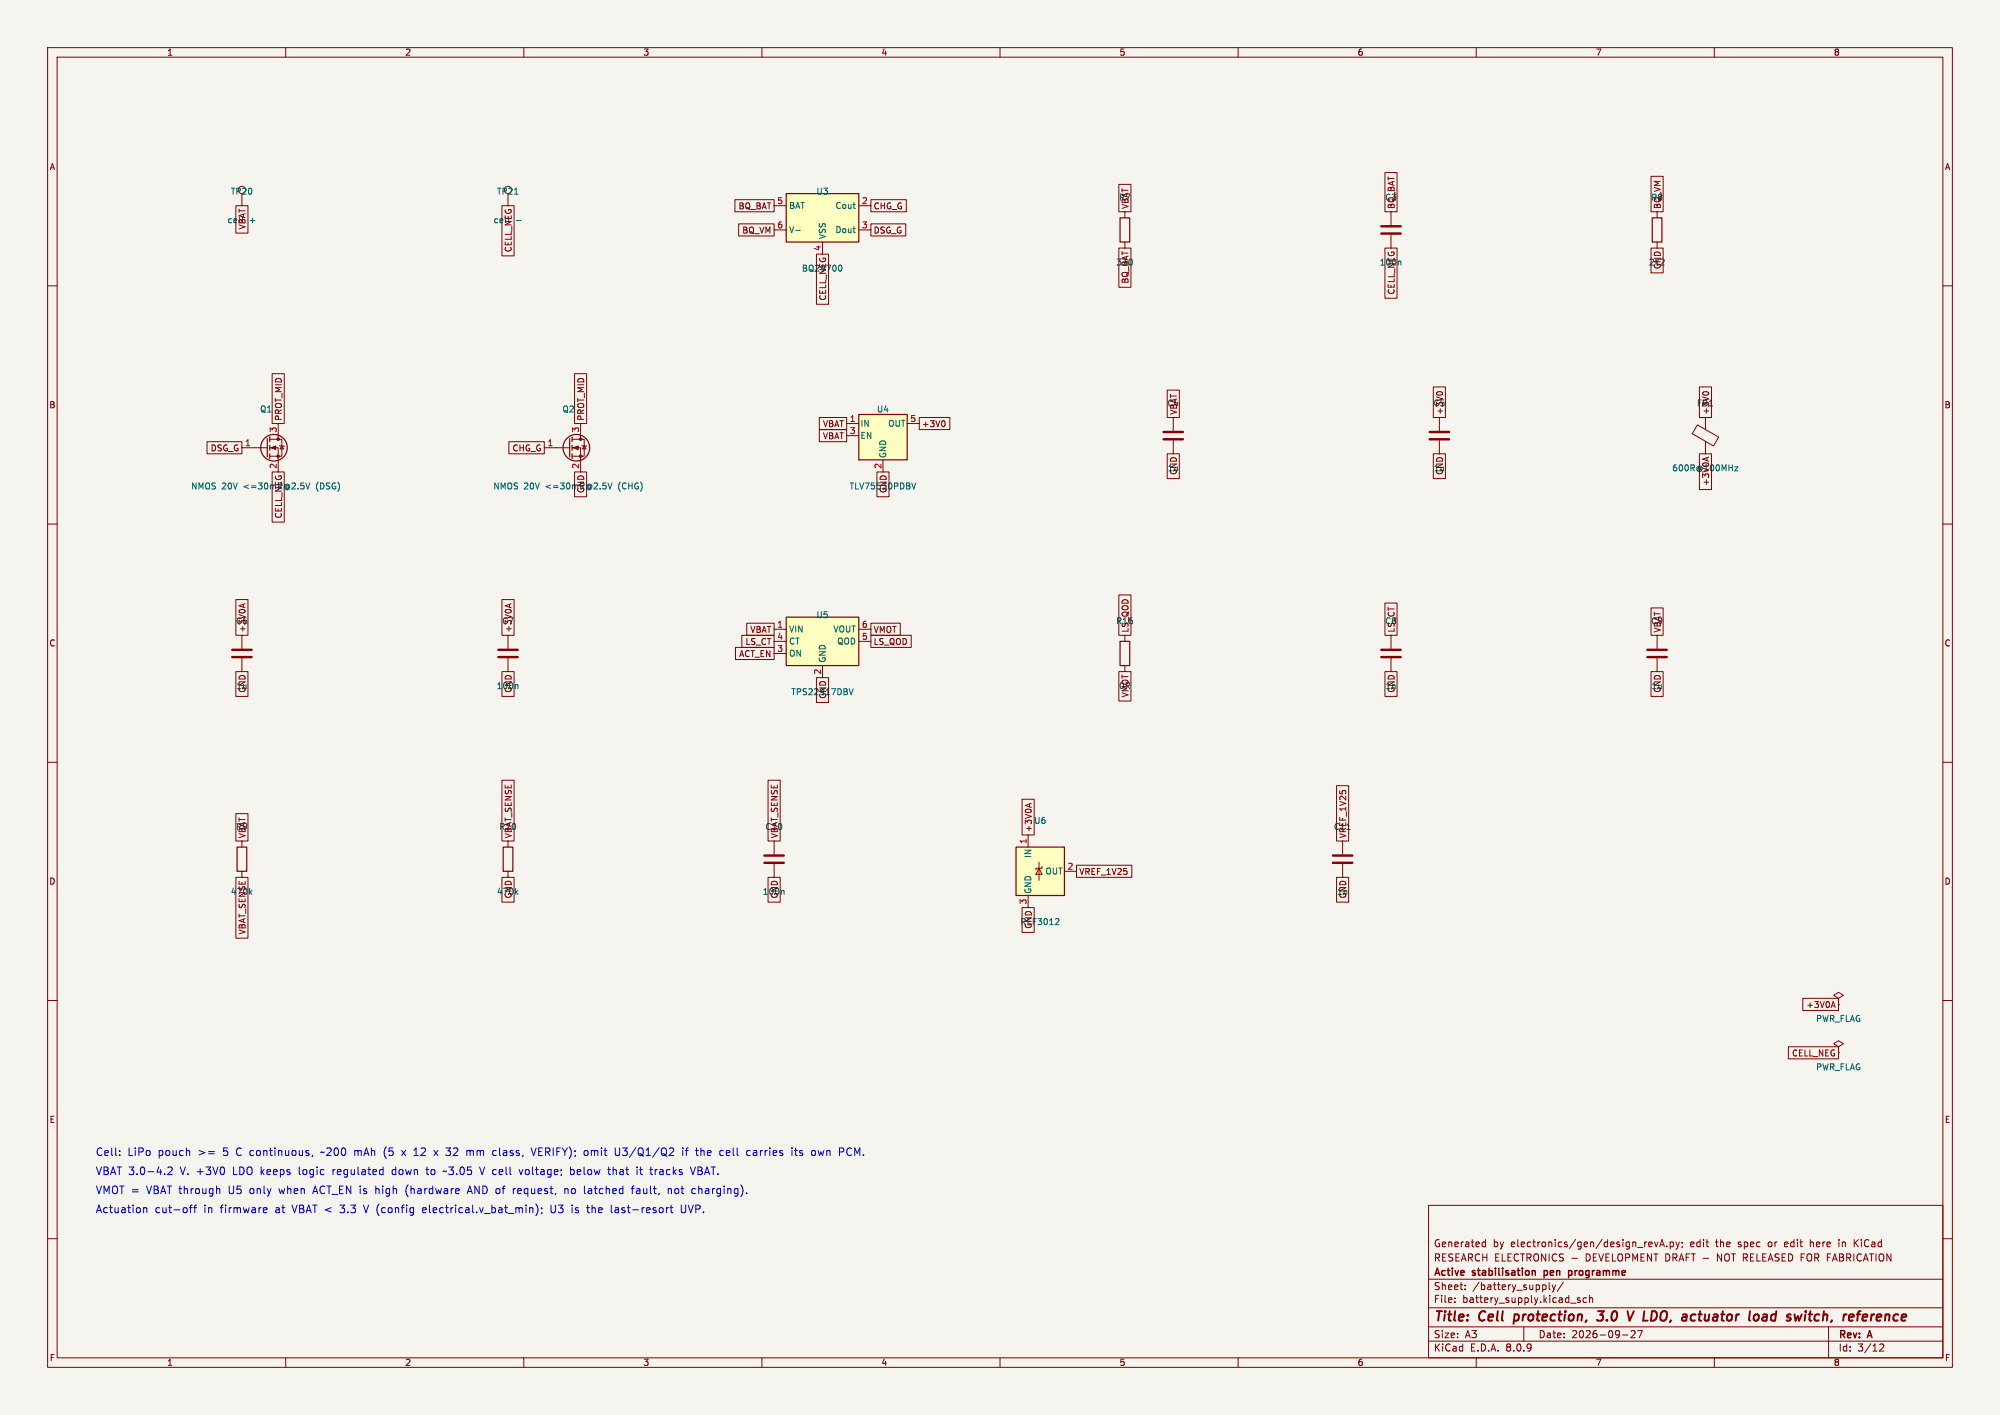
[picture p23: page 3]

2 ON 3 CT 4 QOD 5 VOUT 6 U5 TPS22917DBV
VBAT

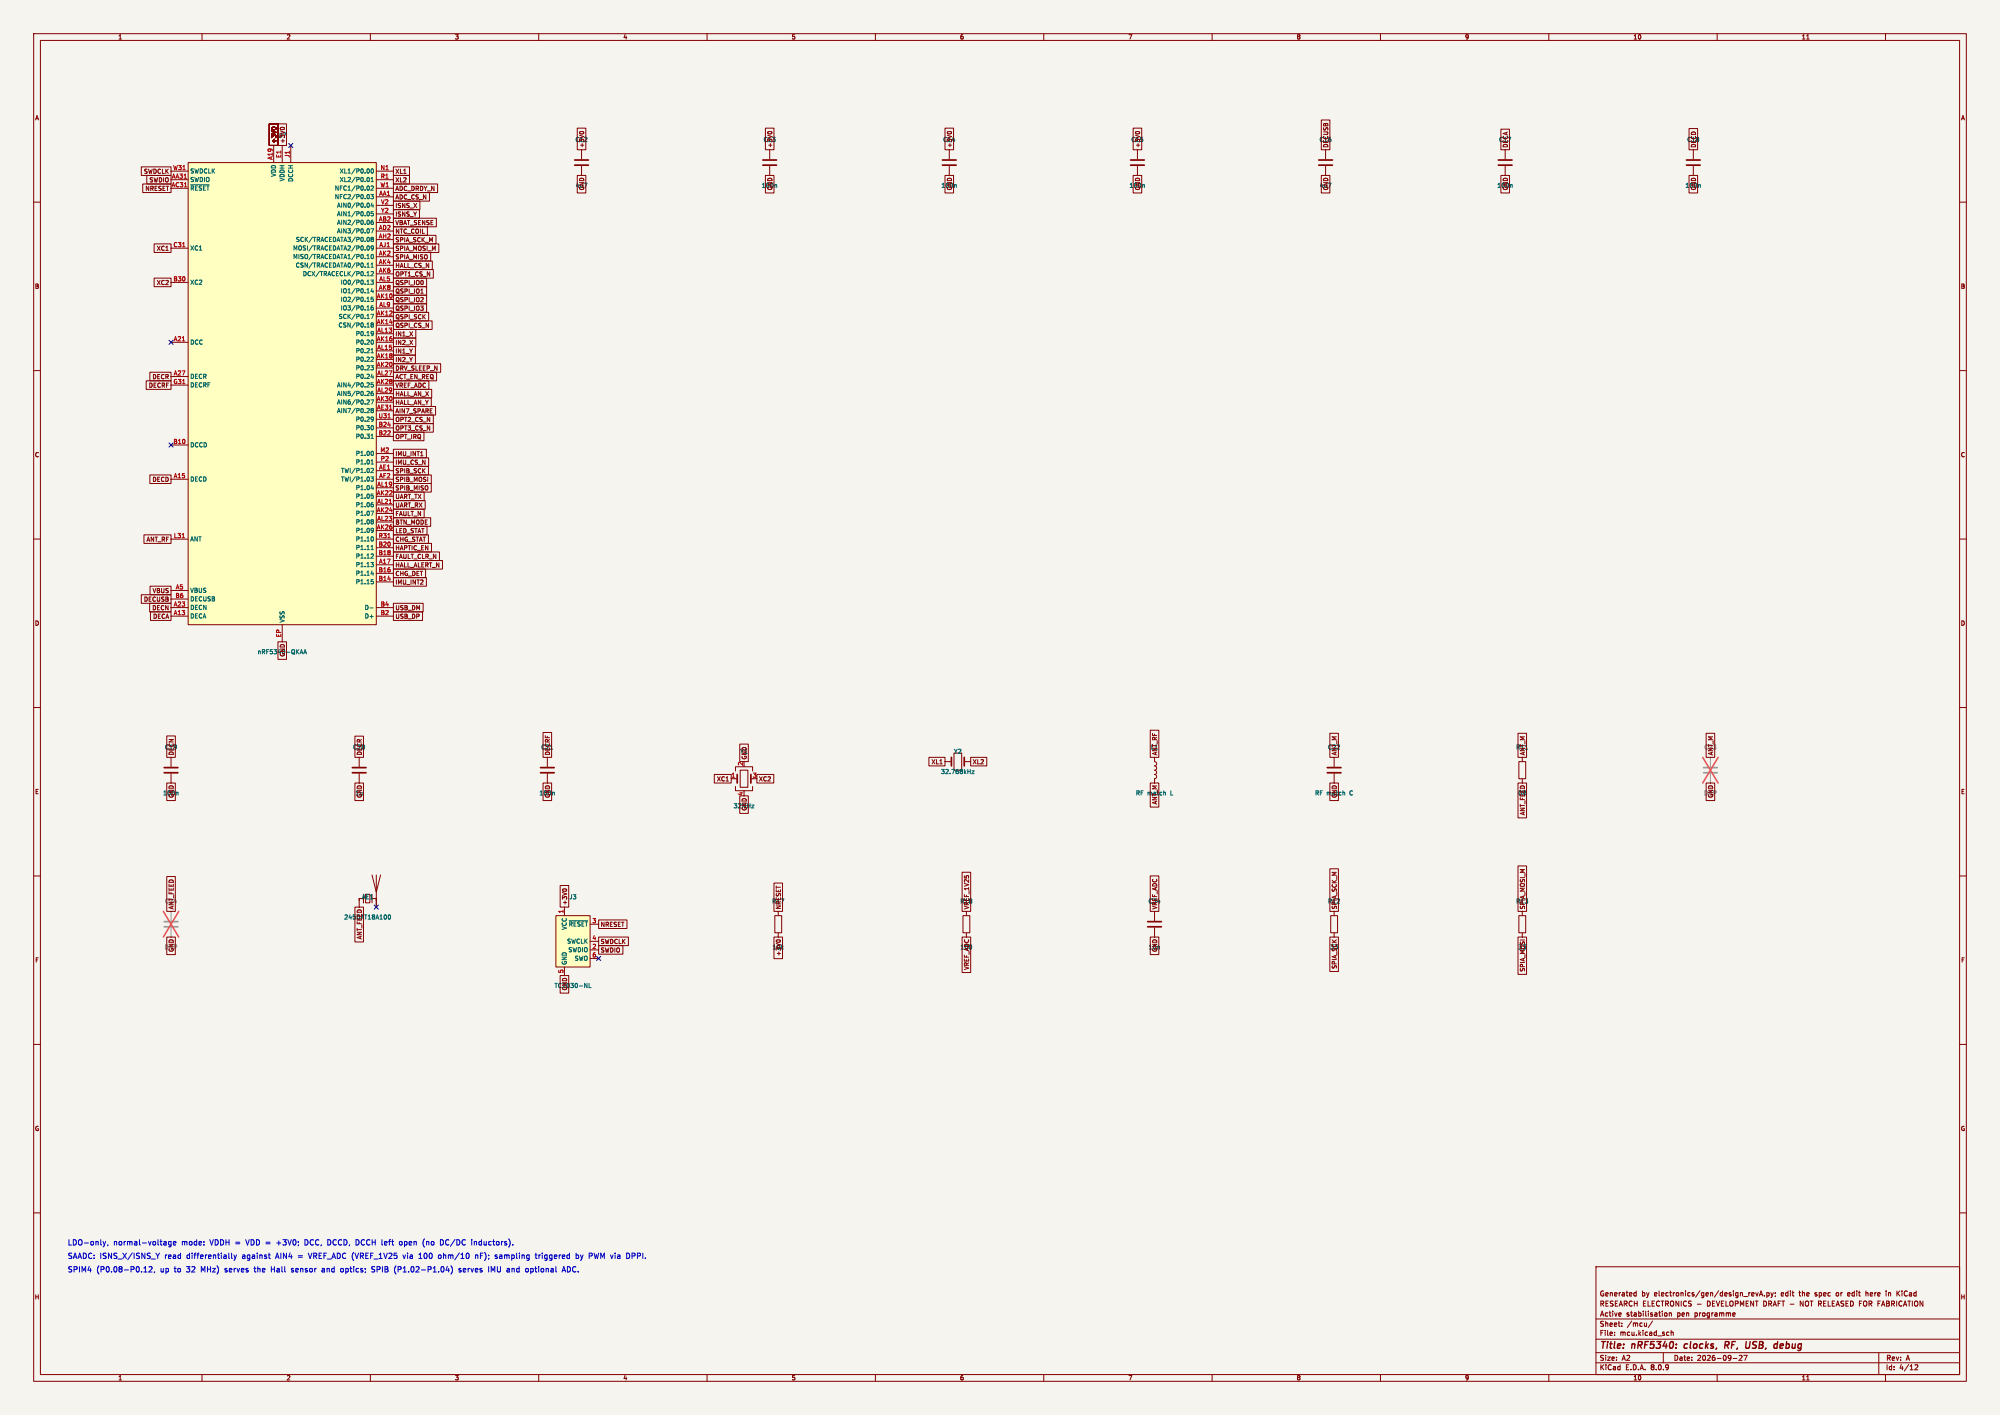
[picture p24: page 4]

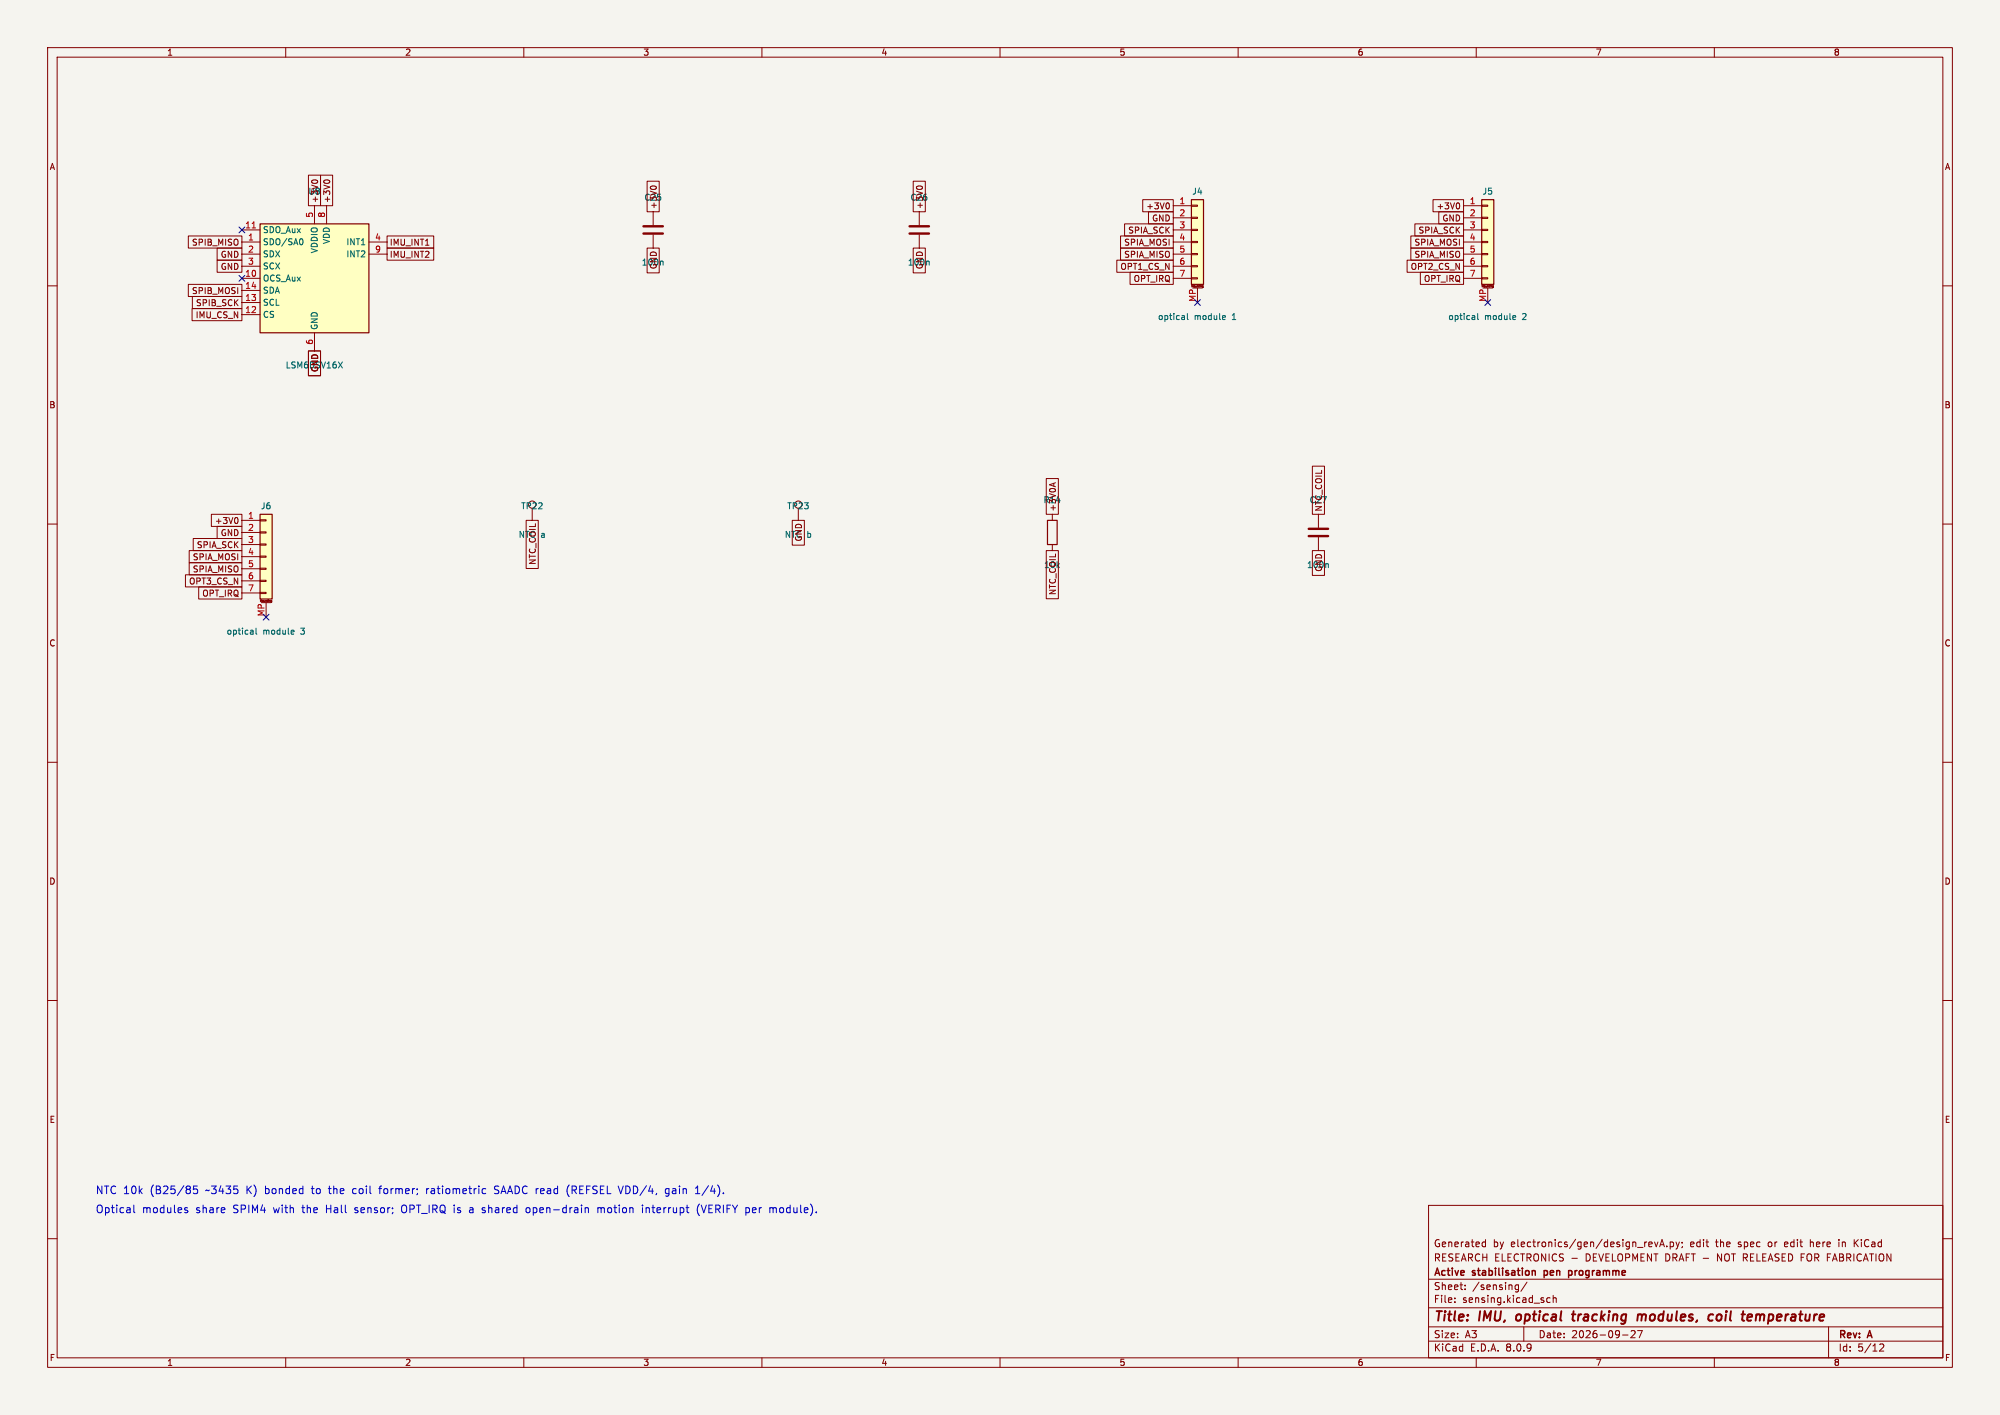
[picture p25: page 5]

Id: 5/12 Title: IMU, optical tracking modules, coil temperature

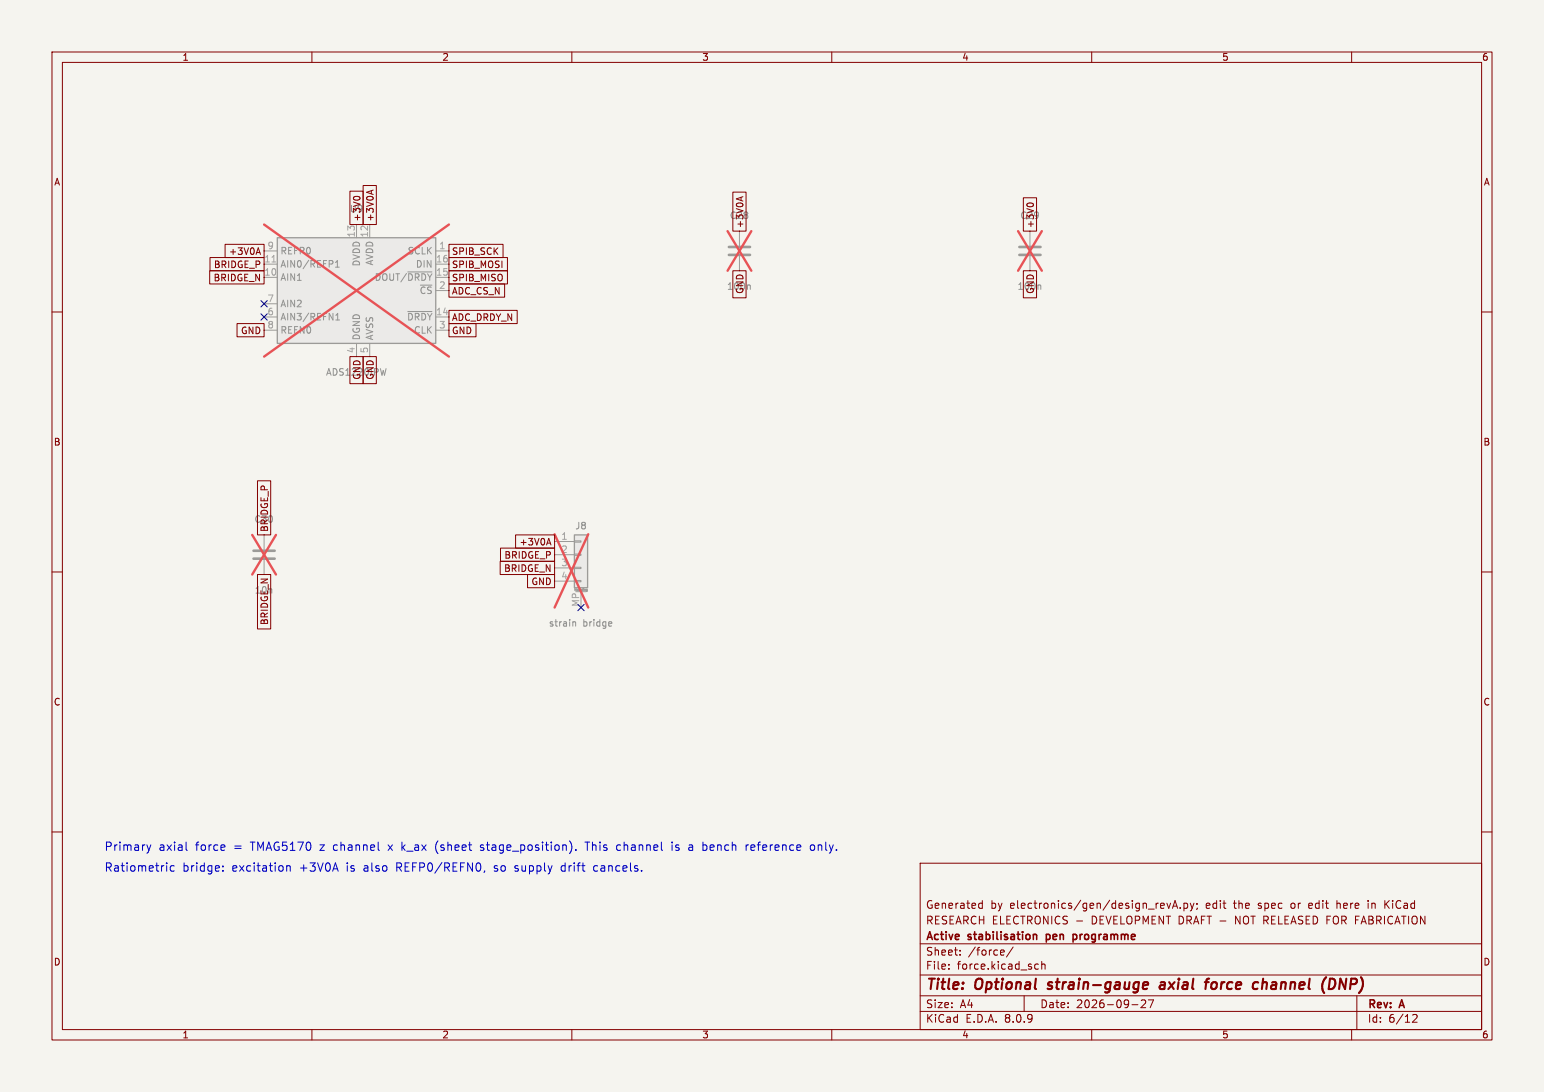
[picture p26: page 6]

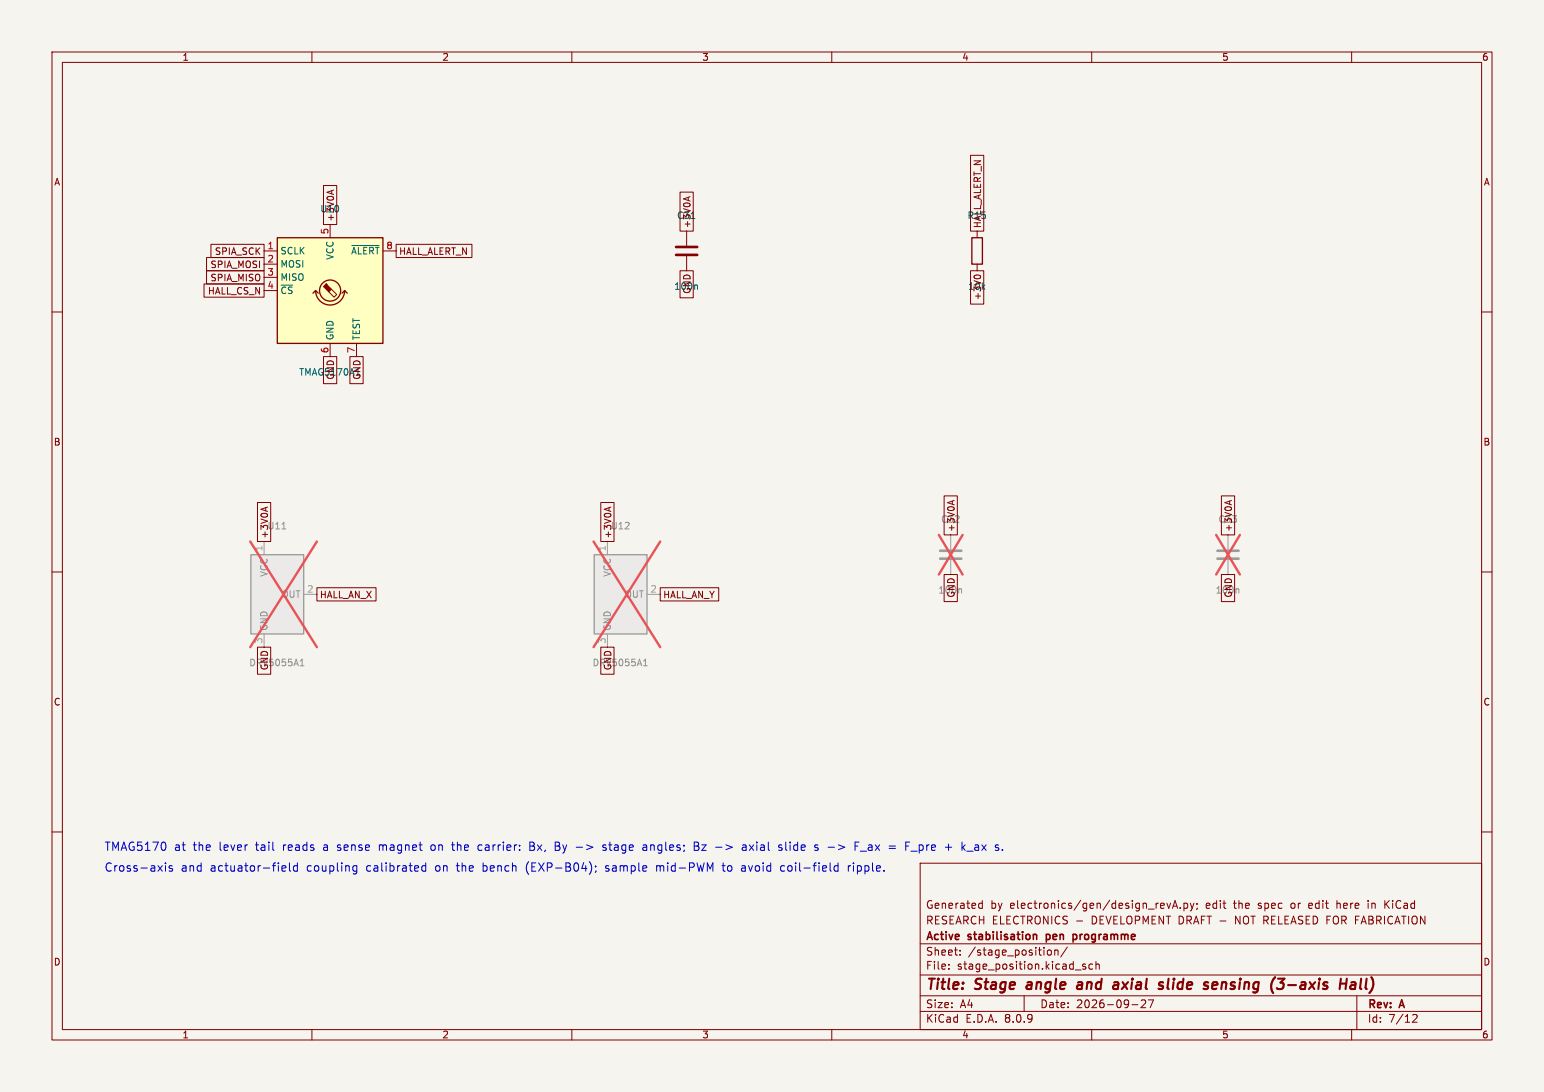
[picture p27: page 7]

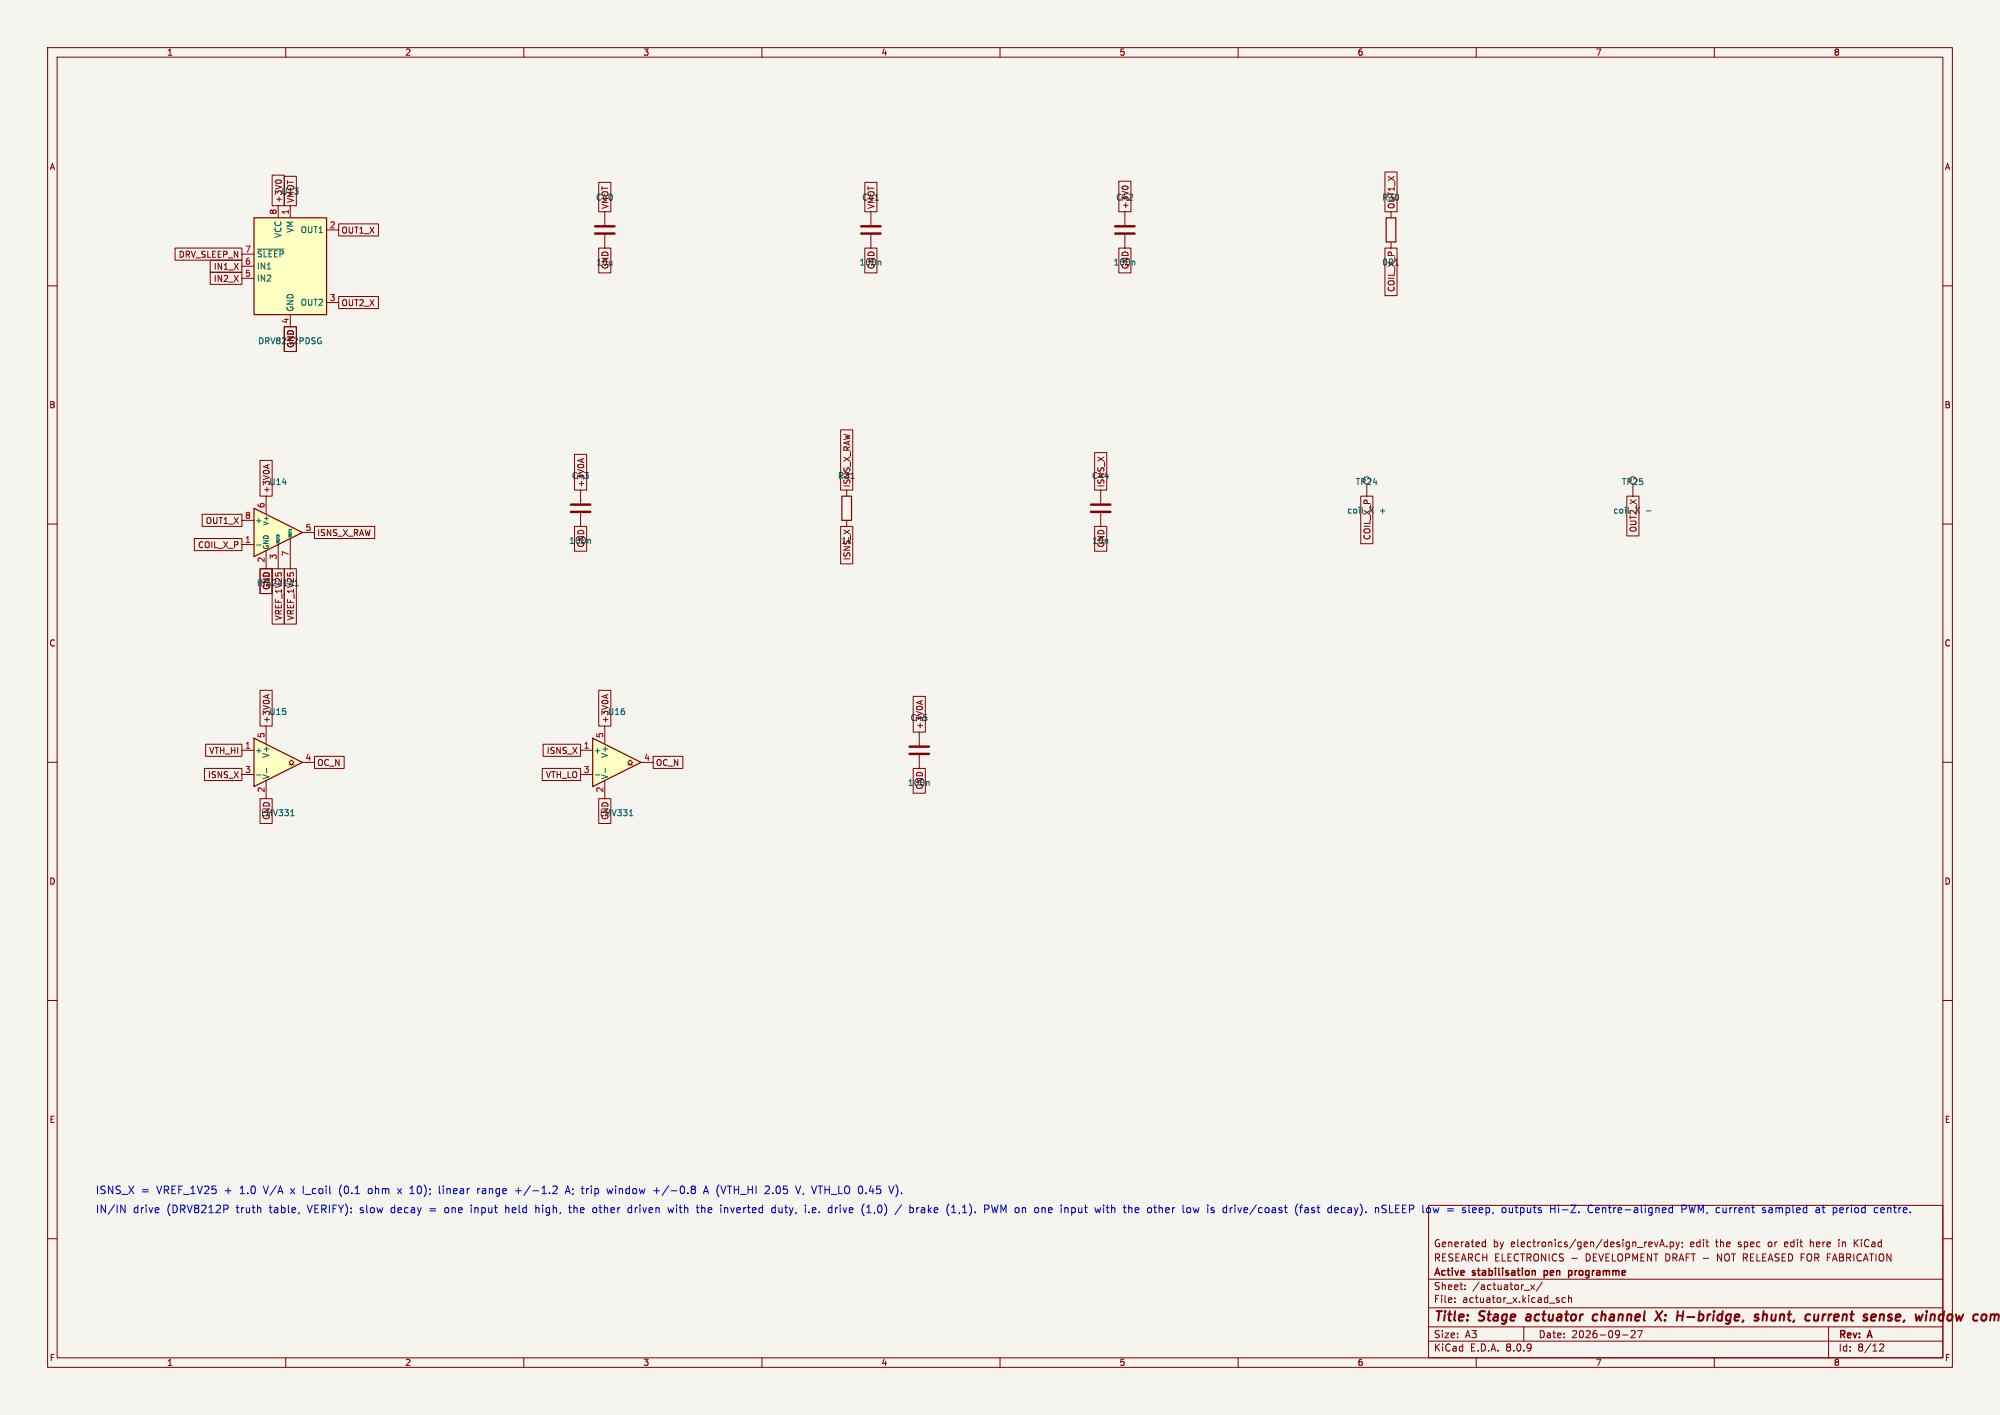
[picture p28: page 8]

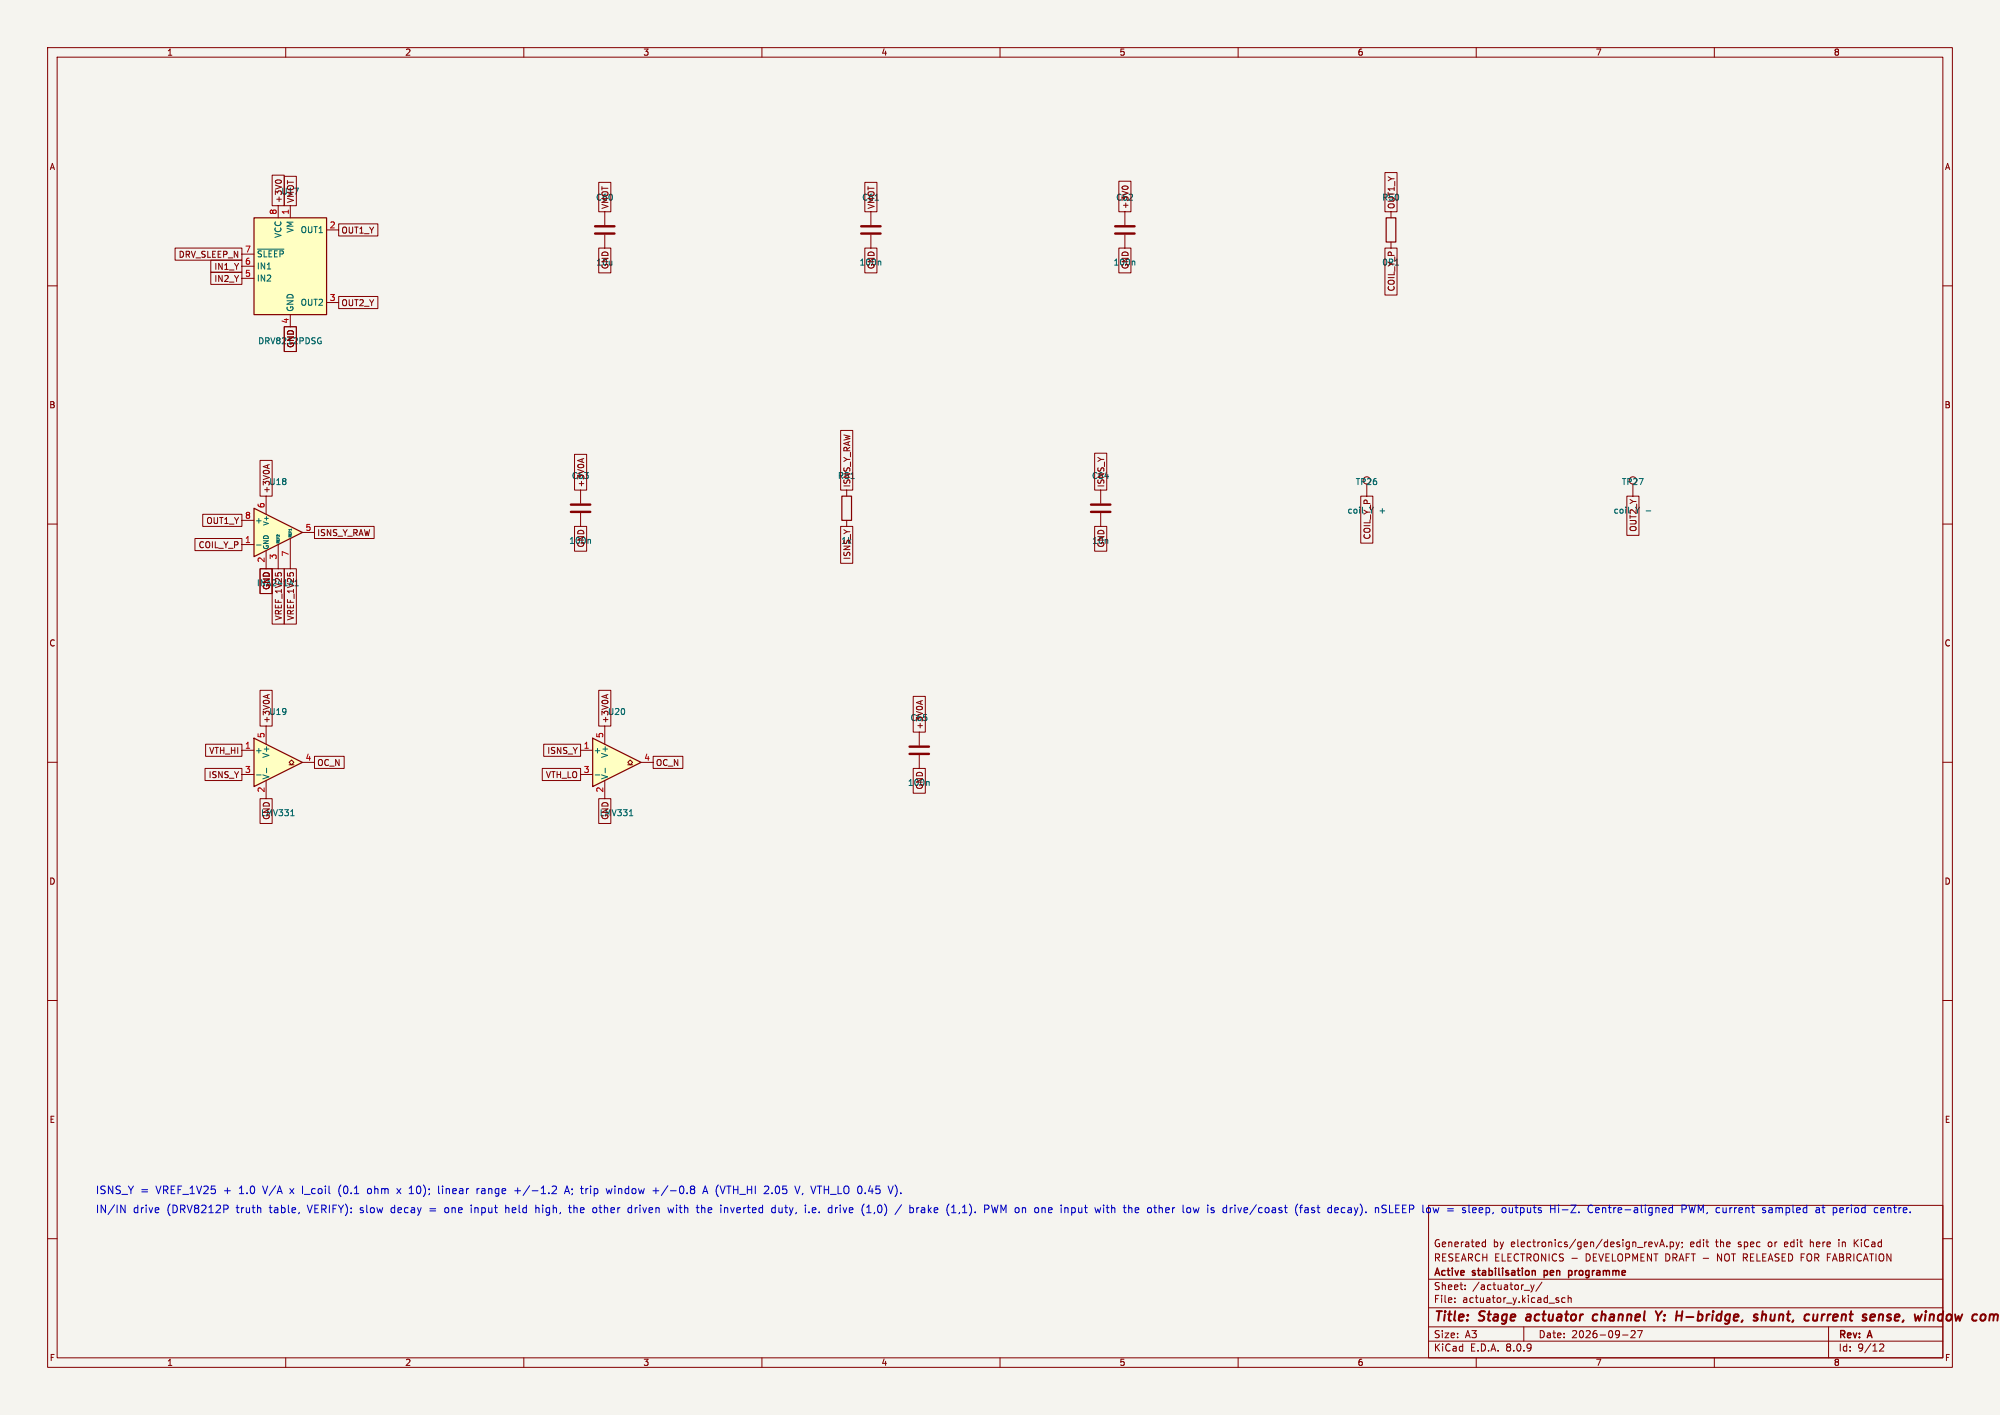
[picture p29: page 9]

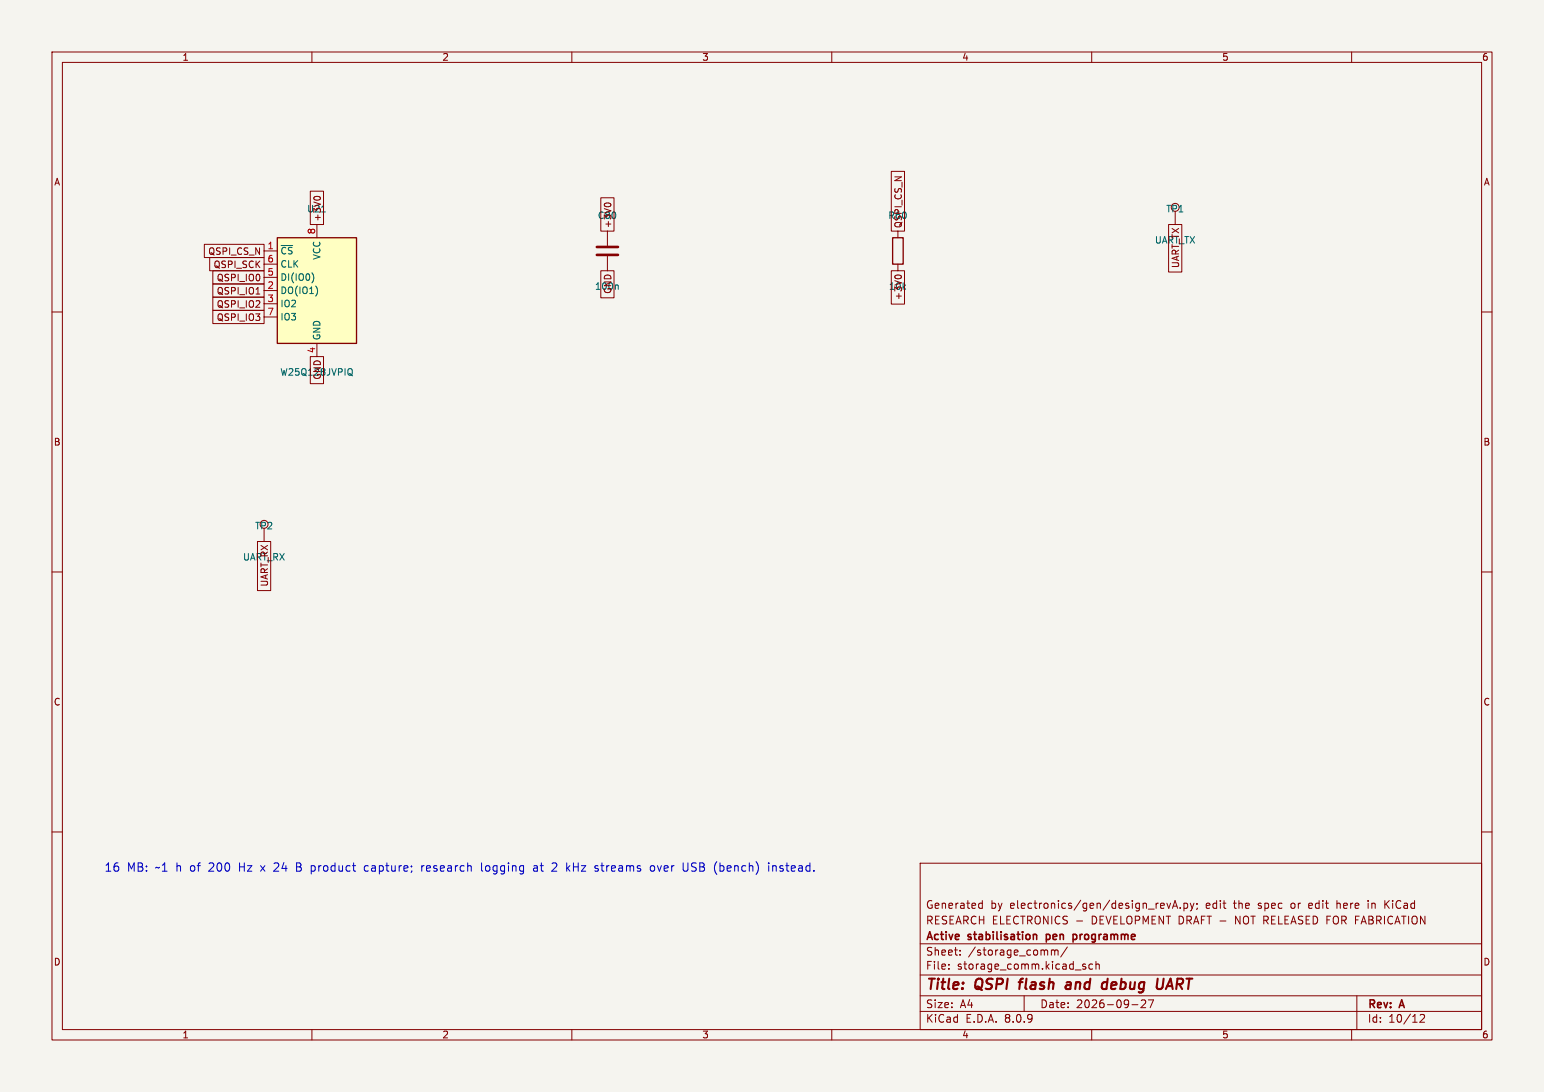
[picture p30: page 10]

Id: 10/12 Title: QSPI flash and debug UART

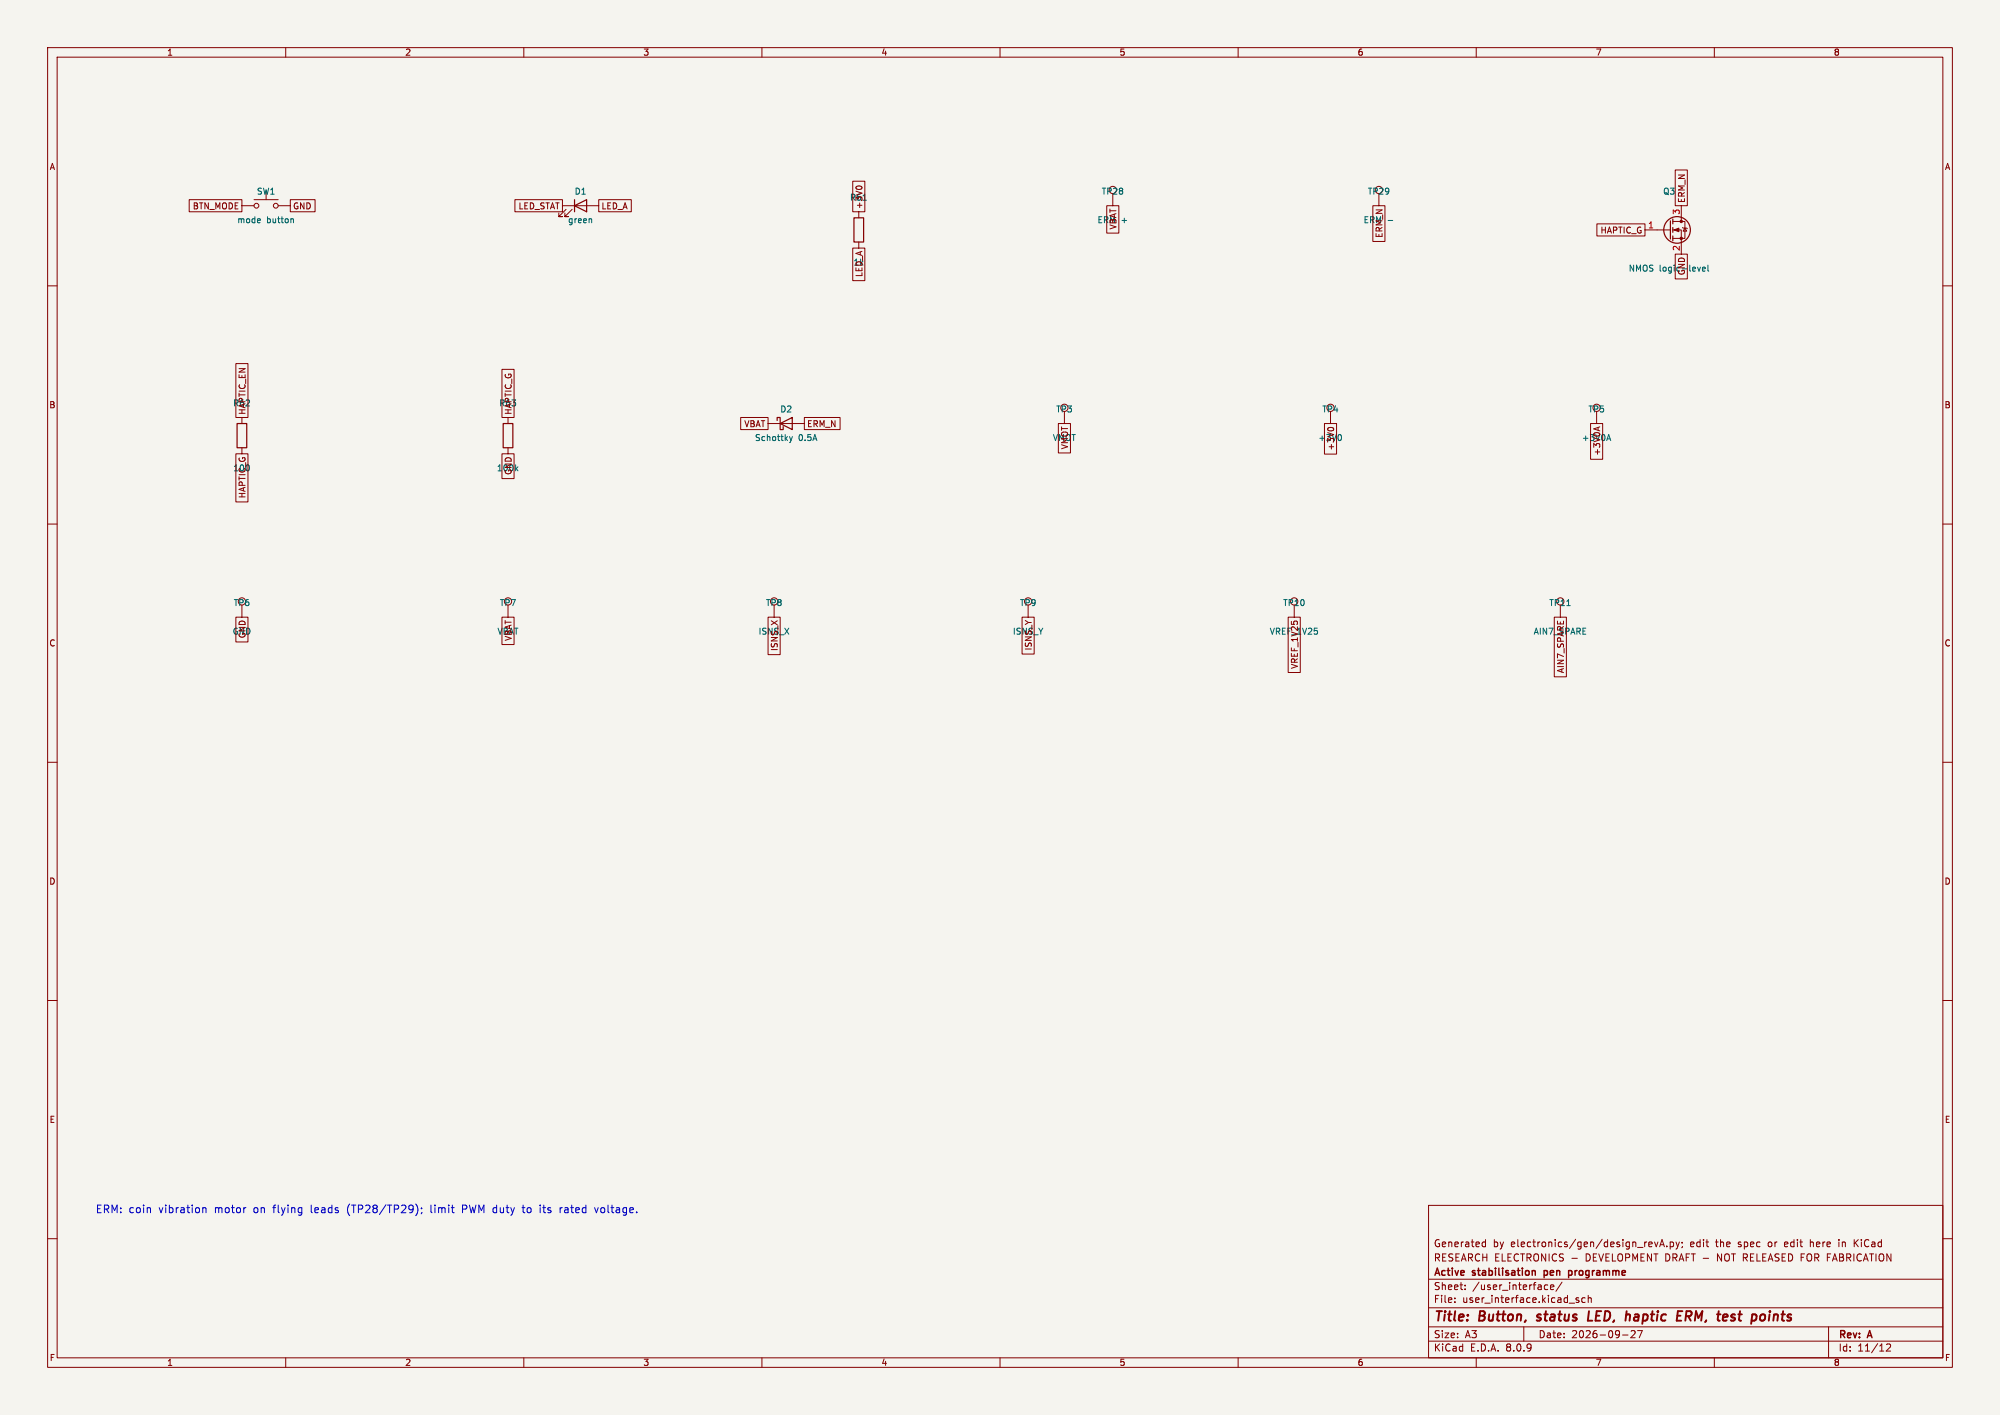
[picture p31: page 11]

Id: 11/12 Title: Button, status LED, haptic ERM, test points

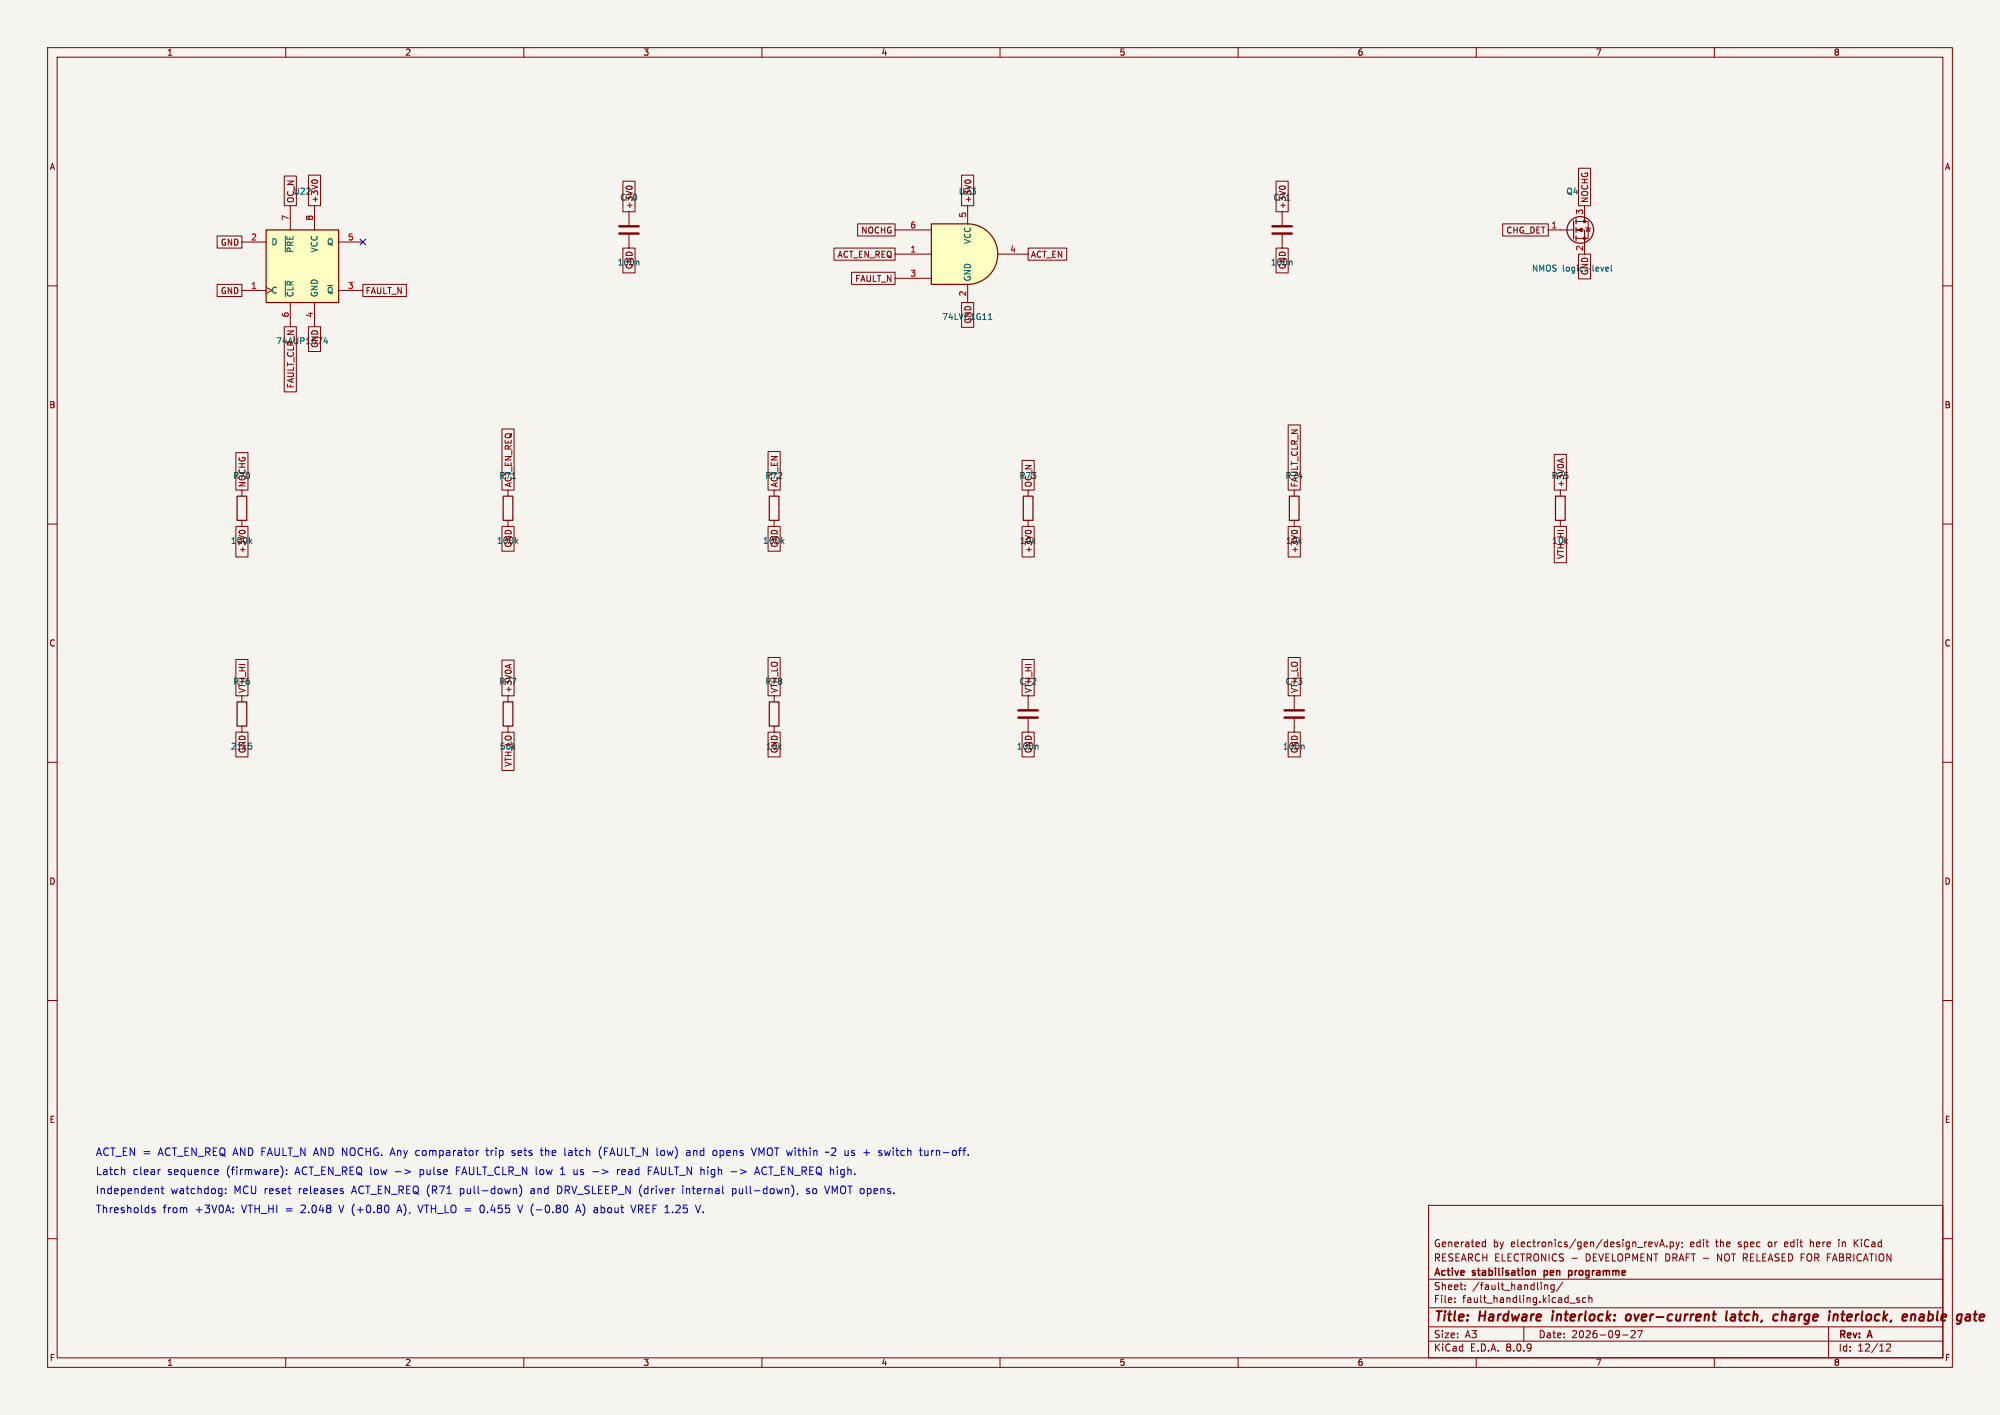
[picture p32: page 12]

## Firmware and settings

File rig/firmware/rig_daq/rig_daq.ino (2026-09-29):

// rig_daq.ino -- DAQ-1 firmware for the study-M measurement rigs (R9-R14): one clock for every channel.
//
// Evidence status: PROPOSED DESIGN. NOT COMPILED OR RUN in this study (no Teensy toolchain in the container).
// Build: Arduino IDE >= 2.3.10 with Teensyduino 1.62 (MFR AMF-237), board "Teensy 4.1", USB Type "Serial",
// CPU 600 MHz. Library: QuadEncoder (file QuadEncoder.h, MFR AMF-238). First bring-up steps in
// docs/measurement_rig.md section 1.3 (loop-back tests before any rig is connected).
//
// What it does, in one interrupt per ADC conversion (ADS131M08 DRDY, 1/2/4/8 kSPS):
//   stamp the 64-bit cycle count -> read the ADS131M08 frame (8 channels, simultaneous) -> latch the four
//   hardware quadrature counters -> compute the disturbance command (multitone, sweep or hold) and run the
//   stage servo (R13) or the current setpoint (R12) -> camera trigger, strobe and coded sync pulse -> one
//   68-byte SAMPLE frame into a ring buffer that loop() drains to USB.
// Datasheet facts used (ADS131M08, SBAS950B, MFR AMF-222): SPI mode 1 (CPOL 0, CPHA 1); 24-bit words, a
// 10-word frame (response, 8 channels, CRC); commands NULL 0x0000, WREG 011a aaaa annn nnnn; MODE 0x02
// (reset 0x0510), CLOCK 0x03 (reset 0xFF0E, OSR[4:2], PWR[1:0]), GAIN1 0x04 / GAIN2 0x05 (3-bit PGA codes,
// 0 = 1 ... 7 = 128); SYNC/RESET low >= 2048 CLKIN periods resets; data rate f_CLKIN / (2 OSR).
// LSM6DSV16X registers from ST's lsm6dsv16x_reg.h (MFR OPT-92). MAX31856 and page-sensor register
// addresses marked UNVERIFIED were NOT checked against a data sheet in this study: verify before use.

#include <SPI.h>
#include <IntervalTimer.h>
#include "QuadEncoder.h"
#include "rig_protocol.h"

#define FW_VERSION "rig_daq 0.1 (study M, proposed)"

// ------------------------------------------------------------------------------------------ pins (doc 1.2)
const int PIN_ADC_CS = 10, PIN_ADC_DRDY = 9, PIN_ADC_SYNCRST = 6;           // SPI0: 11 MOSI, 12 MISO, 13 SCK
const int PIN_CAM = 24, PIN_STROBE = 25, PIN_SYNC_OUT = 28, PIN_DUT_IN = 29, PIN_MARKER = 32;
const int PIN_PWM_A = 22, PIN_PWM_B = 23;                                     // -> RC -> OPA548 current amps
const int PIN_IMU_CS = 38, PIN_PAGE_CS = 36, PIN_IMU_INT1 = 35, PIN_PAGE_MOTION = 34;   // SPI1: 26, 27, 39
const int PIN_TC_CS[4] = {0, 1, 14, 15};                                      // MAX31856 on SPI0

QuadEncoder enc1(1, 2, 3, 0), enc2(2, 4, 7, 0), enc3(3, 8, 30, 0), enc4(4, 31, 33, 0);

SPISettings adcSPI(16000000, MSBFIRST, SPI_MODE1);    // SCLK period >= 40 ns allowed; 16 MHz: 15 us per frame
SPISettings tcSPI(4000000, MSBFIRST, SPI_MODE1);      // MAX31856 (UNVERIFIED: mode 1 or 3, <= 5 MHz)
SPISettings imuSPI(8000000, MSBFIRST, SPI_MODE3);     // LSM6DSV16X
SPISettings pageSPI(2000000, MSBFIRST, SPI_MODE3);    // PMW3901-class page sensors (UNVERIFIED)

// ------------------------------------------------------------------------------------------ one clock
static volatile uint32_t cyc_hi = 0, cyc_last = 0;
static inline uint64_t now_cyc() {
  uint32_t primask;
  __asm__ volatile("mrs %0, primask" : "=r"(primask));
  __disable_irq();
  uint32_t c = ARM_DWT_CYCCNT;
  if (c < cyc_last) cyc_hi++;           // wraps every 7.2 s at 600 MHz; the DRDY ISR calls this >= 1000 times/s
  cyc_last = c;
  uint64_t t = ((uint64_t)cyc_hi << 32) | c;
  if (!primask) __enable_irq();
  return t;
}

// ------------------------------------------------------------------------------------------ ring buffer
static const uint32_t RB_SIZE = 1u << 17;             // 128 KiB: 1.7 s of SAMPLE frames at 4 kSPS
DMAMEM static uint8_t rb[RB_SIZE];
static volatile uint32_t rb_head = 0, rb_tail = 0, rb_dropped = 0;
static volatile bool overrun_flag = false;

static bool rb_push(const uint8_t *p, uint32_t n) {   // called with interrupts masked or from the ISR
  uint32_t h = rb_head, t = rb_tail;
  uint32_t used = (h - t) & (RB_SIZE - 1);
  if (RB_SIZE - 1 - used < n) { rb_dropped++; overrun_flag = true; return false; }
  for (uint32_t i = 0; i < n; i++) rb[(h + i) & (RB_SIZE - 1)] = p[i];
  __asm__ volatile("dmb" ::: "memory");
  rb_head = (h + n) & (RB_SIZE - 1);
  return true;
}

static void push_frame(uint8_t type, const void *payload, uint8_t len) {
  uint8_t buf[262];
  uint32_t n = rig_frame(buf, type, payload, len);
  uint32_t primask;
  __asm__ volatile("mrs %0, primask" : "=r"(primask));
  __disable_irq();
  rb_push(buf, n);
  if (!primask) __enable_irq();
}

static volatile uint32_t ev_seq = 0;
static volatile bool running = false;
static void push_event(uint8_t kind, uint32_t value, uint64_t t) {
  if (!running) return;                                   // edges keep happening; they are logged only while running
  EventPayload e = {};
  e.seq = ev_seq++;
  e.t_cyc = t;
  e.kind = kind;
  e.value = value;
  push_frame(T_EVENT, &e, sizeof(e));
}

static void push_text(const char *s, uint8_t type = T_TEXT) {
  size_t n = strlen(s);
  if (n > 255) n = 255;
  push_frame(type, s, (uint8_t)n);
}

// ------------------------------------------------------------------------------------------ ADS131M08
static const uint8_t ADC_WORDS = 10, ADC_WB = 3;      // 24-bit words
static uint8_t adc_gain_code[8] = {7, 7, 7, 7, 0, 0, 0, 0};   // 128 on the bridges, 1 elsewhere (doc 1.2)
static uint8_t adc_osr_code = 3;                               // 1024 -> 4 kSPS at 8.192 MHz
static volatile uint32_t adc_rate = 4000;

static void adc_frame(const uint16_t *cmd_words, uint8_t n_cmd, uint8_t *rx) {
  // one full frame: command words MSB-aligned in 24-bit words, zeros after; rx gets 30 bytes
  uint8_t tx[ADC_WORDS * ADC_WB] = {0};
  for (uint8_t i = 0; i < n_cmd && i < ADC_WORDS; i++) {
    tx[i * ADC_WB] = cmd_words[i] >> 8;
    tx[i * ADC_WB + 1] = cmd_words[i] & 0xFF;
  }
  SPI.beginTransaction(adcSPI);
  digitalWriteFast(PIN_ADC_CS, LOW);
  for (uint8_t i = 0; i < ADC_WORDS * ADC_WB; i++) rx[i] = SPI.transfer(tx[i]);
  digitalWriteFast(PIN_ADC_CS, HIGH);
  SPI.endTransaction();
}

static void adc_wreg(uint8_t addr, uint16_t value) {
  uint16_t w[2] = {(uint16_t)(0x6000 | ((uint16_t)addr << 7)), value};   // WREG, one register (nnn nnnn = 0)
  uint8_t rx[ADC_WORDS * ADC_WB];
  adc_frame(w, 2, rx);
  delayMicroseconds(20);
}

static uint16_t adc_rreg(uint8_t addr) {
  uint16_t w[1] = {(uint16_t)(0xA000 | ((uint16_t)addr << 7))};          // RREG, one register
  uint8_t rx[ADC_WORDS * ADC_WB];
  adc_frame(w, 1, rx);
  uint16_t z[1] = {0x0000};                                               // the reply comes in the next frame
  adc_frame(z, 1, rx);
  return ((uint16_t)rx[0] << 8) | rx[1];
}

static void adc_configure() {
  adc_wreg(0x02, 0x0110);                                   // MODE: 24-bit, SPI timeout on, clear RESET flag
  adc_wreg(0x03, (uint16_t)(0xFF00 | (adc_osr_code << 2) | 0x2));   // CLOCK: all channels, OSR, high resolution
  uint16_t g1 = 0, g2 = 0;
  for (int c = 0; c < 4; c++) g1 |= (uint16_t)(adc_gain_code[c] & 7) << (4 * c);
  for (int c = 0; c < 4; c++) g2 |= (uint16_t)(adc_gain_code[4 + c] & 7) << (4 * c);
  adc_wreg(0x04, g1);                                       // GAIN1 (channels 0-3)
  adc_wreg(0x05, g2);                                       // GAIN2 (channels 4-7)
  static const uint16_t osr_val[8] = {128, 256, 512, 1024, 2048, 4096, 8192, 16256};
  adc_rate = (uint32_t)(8192000UL / (2UL * osr_val[adc_osr_code]));
}

static void adc_reset() {
  digitalWriteFast(PIN_ADC_SYNCRST, LOW);
  delayMicroseconds(400);                                   // >= 2048 CLKIN periods (250 us at 8.192 MHz)
  digitalWriteFast(PIN_ADC_SYNCRST, HIGH);
  delayMicroseconds(50);                                    // >= t_REGACQ (5 us)
}

// ------------------------------------------------------------------------------------------ disturbance command
struct Tone { float f, amp, phase; };
static Tone tones[32];
static volatile uint8_t n_tones = 0;
static volatile bool sweep_on = false;
static float sweep_f0 = 1, sweep_f1 = 30, sweep_T = 10, sweep_amp = 0;
static volatile int32_t hold_counts = 0;
static volatile uint32_t wave_tick = 0;
static volatile bool wave_on = false;

static int32_t command_counts() {
  if (!wave_on) return hold_counts;
  double t = (double)wave_tick / (double)adc_rate;
  double x = 0;
  if (sweep_on) {                                             // exponential (log) sweep, restarts every T
    double tt = fmod(t, (double)sweep_T);
    double k = log((double)sweep_f1 / sweep_f0);
    double ph = 2 * M_PI * sweep_f0 * sweep_T / k * (exp(tt / sweep_T * k) - 1.0);
    x = sweep_amp * sin(ph);
  } else {
    for (uint8_t i = 0; i < n_tones; i++) x += tones[i].amp * sin(2 * M_PI * tones[i].f * t + tones[i].phase);
  }
  wave_tick++;
  return hold_counts + (int32_t)lround(x);
}

// servo (R13): current = KP e + KI int(e) + KD de + KFF a_cmd; e and a_cmd in encoder counts
static volatile bool dist_loop = false, current_loop = false;
static float KP = 0, KI = 0, KD = 0, KFF = 0, ILIM_A = 1.0f, ISCALE_A = 3.0f;   // ISCALE: amps at full PWM swing
static float integ = 0, e_last = 0;
static int32_t cmd_hist[3] = {0, 0, 0};
static volatile int32_t trip_err = 4000, trip_pos = 12000;      // counts (1 mm, 3 mm at 0.244 um/count)
static volatile float iset_A = 0;                                 // R12 current setpoint
static volatile bool governor = false;

static void write_current(int pin, float amps) {
  bool lim = false;
  if (amps > ILIM_A) { amps = ILIM_A; lim = true; }
  if (amps < -ILIM_A) { amps = -ILIM_A; lim = true; }
  governor = lim;
  int duty = 2048 + (int)lroundf(2047.0f * amps / ISCALE_A);     // mid-scale = 0 A (bipolar current amp)
  if (duty < 0) duty = 0;
  if (duty > 4095) duty = 4095;
  analogWrite(pin, duty);
}

// ------------------------------------------------------------------------------------------ camera, strobe, sync
static volatile uint32_t cam_div = 40, cam_count = 0, strobe_delay_us = 200, strobe_width_us = 30;
static volatile bool cam_on = false, cam_high = false, sync_on = true, sync_high = false;
static volatile uint32_t sync_tick = 0;
static volatile uint8_t sync_n = 0;
IntervalTimer strobeOn, strobeOff, syncFall;

static void strobe_off_cb() {
  digitalWriteFast(PIN_STROBE, LOW);
  strobeOff.end();
}
static void strobe_on_cb() {
  strobeOn.end();
  digitalWriteFast(PIN_STROBE, HIGH);
  push_event(EV_STROBE, cam_count, now_cyc());
  strobeOff.begin(strobe_off_cb, strobe_width_us);
}
static void sync_fall_cb() {
  syncFall.end();
  digitalWriteFast(PIN_SYNC_OUT, LOW);
  sync_high = false;
  push_event(EV_SYNC_OUT_FALL, sync_n, now_cyc());
  sync_n++;
}

// ------------------------------------------------------------------------------------------ thermocouples (MAX31856)
static volatile uint8_t tc_mask = 0, tc_next = 0;
static volatile uint32_t tc_div = 400, tc_count = 0;

static uint32_t tc_read_raw(int ch) {                      // UNVERIFIED: LTCBH 0x0C, LTCBM 0x0D, LTCBL 0x0E
  SPI.beginTransaction(tcSPI);
  digitalWriteFast(PIN_TC_CS[ch], LOW);
  SPI.transfer(0x0C);
  uint32_t b2 = SPI.transfer(0), b1 = SPI.transfer(0), b0 = SPI.transfer(0);
  digitalWriteFast(PIN_TC_CS[ch], HIGH);
  SPI.endTransaction();
  return (b2 << 16) | (b1 << 8) | b0;
}

static void tc_init(int ch) {                              // UNVERIFIED: CR0 0x00 (0x80 auto conversion), CR1 0x01 (type T = 0x07)
  SPI.beginTransaction(tcSPI);
  digitalWriteFast(PIN_TC_CS[ch], LOW);
  SPI.transfer(0x80 | 0x00);
  SPI.transfer(0x80);
  SPI.transfer(0x07);
  digitalWriteFast(PIN_TC_CS[ch], HIGH);
  SPI.endTransaction();
}

// ------------------------------------------------------------------------------------------ the DRDY interrupt
static volatile uint32_t sample_seq = 0;

static void drdy_isr() {
  uint64_t t = now_cyc();
  uint8_t rx[ADC_WORDS * ADC_WB];
  uint16_t nul[1] = {0x0000};
  adc_frame(nul, 1, rx);
  int32_t e0 = enc1.read(), e1 = enc2.read(), e2 = enc3.read(), e3 = enc4.read();

  SamplePayload s = {};                                     // the servo, camera and sync run whether or not we log
  s.seq = sample_seq++;
  s.t_cyc = t;
  uint8_t status_lo = rx[1];
  s.nadc = (uint8_t)__builtin_popcount(status_lo);           // STATUS DRDY bits of the eight channels
  for (int c = 0; c < 8; c++) {
    const uint8_t *w = &rx[(1 + c) * ADC_WB];
    int32_t v = ((int32_t)w[0] << 16) | ((int32_t)w[1] << 8) | w[2];
    if (v & 0x800000) v -= 0x1000000;
    s.adc[c] = v;
  }
  s.enc[0] = e0; s.enc[1] = e1; s.enc[2] = e2; s.enc[3] = e3;

  int32_t cmd = command_counts();
  s.cmd = cmd;
  uint16_t flags = 0;

  if (dist_loop) {                                            // R13 stage on encoder channel 3 (enc[2])
    if (abs(e2 - cmd) > trip_err || abs(e2) > trip_pos) {
      dist_loop = false;
      write_current(PIN_PWM_A, 0);
      push_text("TRIP: disturbance loop off (error or position limit)");
    } else {
      float e = (float)(cmd - e2);
      float dt = 1.0f / (float)adc_rate;
      integ += e * dt;
      float de = (e - e_last) / dt;
      e_last = e;
      cmd_hist[2] = cmd_hist[1]; cmd_hist[1] = cmd_hist[0]; cmd_hist[0] = cmd;
      float acc = (float)(cmd_hist[0] - 2 * cmd_hist[1] + cmd_hist[2]) / (dt * dt);
      write_current(PIN_PWM_A, KP * e + KI * integ + KD * de + KFF * acc);
      flags |= F_DIST_LOOP;
    }
  }
  if (current_loop) {                                         // R12 coupon current (amplifier closes the loop)
    write_current(PIN_PWM_B, iset_A);
    flags |= F_CURRENT_LOOP;
  }
  if (governor) flags |= F_GOVERNOR;

  if (cam_on) {
    if (cam_high) { digitalWriteFast(PIN_CAM, LOW); cam_high = false; }
    if (++cam_count % cam_div == 0) {
      digitalWriteFast(PIN_CAM, HIGH);                       // OV9281: frame on the rising edge, >= 2 us (MFR OPT-88)
      cam_high = true;
      uint64_t tc = now_cyc();
      push_event(EV_CAM_TRIGGER, cam_count / cam_div, tc);
      strobeOn.begin(strobe_on_cb, strobe_delay_us);
      flags |= F_CAM;
    }
  }
  if (sync_on && ++sync_tick >= adc_rate) {                  // coded sync: 1 ms + n * 0.25 ms, once per second
    sync_tick = 0;
    digitalWriteFast(PIN_SYNC_OUT, HIGH);
    sync_high = true;
    push_event(EV_SYNC_OUT_RISE, sync_n, now_cyc());
    syncFall.begin(sync_fall_cb, 1000 + 250 * (uint32_t)sync_n);
  }
  if (sync_high) flags |= F_SYNC;
  if (digitalReadFast(PIN_DUT_IN)) flags |= F_DUT;
  if (digitalReadFast(PIN_STROBE)) flags |= F_STROBE;
  if (overrun_flag) { flags |= F_OVERRUN; overrun_flag = false; }
  s.flags = flags;

  if (tc_mask && ++tc_count >= tc_div) {                     // one thermocouple per tc_div ticks, round robin
    tc_count = 0;
    for (int k = 0; k < 4; k++) {
      uint8_t ch = (tc_next + k) & 3;
      if (tc_mask & (1 << ch)) {
        uint32_t raw = tc_read_raw(ch);
        push_event(EV_TEMP, ((uint32_t)ch << 24) | (raw & 0xFFFFFF), now_cyc());
        tc_next = (ch + 1) & 3;
        break;
      }
    }
  }
  if (running) push_frame(T_SAMPLE, &s, sizeof(s));
}

// ------------------------------------------------------------------------------------------ edges from outside
static void dut_isr() {
  uint64_t t = now_cyc();
  push_event(digitalReadFast(PIN_DUT_IN) ? EV_DUT_RISE : EV_DUT_FALL, 0, t);
}
static void marker_isr() { push_event(EV_MARKER, 0xFFFFFFFF, now_cyc()); }

// ------------------------------------------------------------------------------------------ IMU (LSM6DSV16X, recording pen)
static volatile bool imu_on = false, spi1_busy = false, imu_pending = false;
static volatile uint64_t imu_pending_t = 0;
static volatile uint32_t imu_seq = 0;

static void imu_write(uint8_t reg, uint8_t v) {
  SPI1.beginTransaction(imuSPI);
  digitalWriteFast(PIN_IMU_CS, LOW);
  SPI1.transfer(reg & 0x7F);
  SPI1.transfer(v);
  digitalWriteFast(PIN_IMU_CS, HIGH);
  SPI1.endTransaction();
}
static uint8_t imu_read(uint8_t reg) {
  SPI1.beginTransaction(imuSPI);
  digitalWriteFast(PIN_IMU_CS, LOW);
  SPI1.transfer(reg | 0x80);
  uint8_t v = SPI1.transfer(0);
  digitalWriteFast(PIN_IMU_CS, HIGH);
  SPI1.endTransaction();
  return v;
}
static bool imu_init() {
  if (imu_read(0x0F) != 0x70) return false;               // WHO_AM_I = LSM6DSV16X_ID
  imu_write(0x12, 0x01);                                   // CTRL3: SW_RESET
  delay(10);
  imu_write(0x12, 0x44);                                   // CTRL3: BDU (bit 6) + IF_INC (bit 2)
  imu_write(0x15, 0x04);                                   // CTRL6: FS_G = 2000 dps
  imu_write(0x17, 0x03);                                   // CTRL8: FS_XL = 16 g
  imu_write(0x10, 0x0A);                                   // CTRL1: ODR_XL = 1.92 kHz, high-performance
  imu_write(0x11, 0x0A);                                   // CTRL2: ODR_G = 1.92 kHz, high-performance
  imu_write(0x0D, 0x02);                                   // INT1_CTRL: gyroscope data-ready on INT1
  return true;
}
static void imu_read_frame(uint64_t t) {
  uint8_t b[14];
  SPI1.beginTransaction(imuSPI);
  digitalWriteFast(PIN_IMU_CS, LOW);
  SPI1.transfer(0x20 | 0x80);                              // OUT_TEMP_L .. OUTZ_H_A (temp, gyro, accel)
  for (int i = 0; i < 14; i++) b[i] = SPI1.transfer(0);
  digitalWriteFast(PIN_IMU_CS, HIGH);
  SPI1.endTransaction();
  ImuPayload p = {};
  p.seq = imu_seq++;
  p.t_cyc = t;
  p.temp = (int16_t)(b[0] | (b[1] << 8));
  for (int i = 0; i < 3; i++) p.gyr[i] = (int16_t)(b[2 + 2 * i] | (b[3 + 2 * i] << 8));
  for (int i = 0; i < 3; i++) p.acc[i] = (int16_t)(b[8 + 2 * i] | (b[9 + 2 * i] << 8));
  push_frame(T_IMU, &p, sizeof(p));
}
static void imu_isr() {
  uint64_t t = now_cyc();                                  // the data-ready edge is the sample time
  if (!imu_on) return;
  if (spi1_busy) { imu_pending_t = t; imu_pending = true; return; }   // loop() owns SPI1: read it there
  imu_read_frame(t);
}

// ------------------------------------------------------------------------------------------ page sensor (polled in loop)
static volatile bool page_on = false;
static uint32_t page_seq = 0, page_period_us = 1000;
static elapsedMicros page_timer;

static uint8_t page_reg(uint8_t reg) {                   // UNVERIFIED PMW3901-class timing: address, wait, data
  SPI1.beginTransaction(pageSPI);
  digitalWriteFast(PIN_PAGE_CS, LOW);
  SPI1.transfer(reg & 0x7F);
  delayMicroseconds(50);
  uint8_t v = SPI1.transfer(0);
  digitalWriteFast(PIN_PAGE_CS, HIGH);
  SPI1.endTransaction();
  delayMicroseconds(1);
  return v;
}
static void page_poll() {                                // UNVERIFIED: MOTION 0x02, DX 0x03/0x04, DY 0x05/0x06, SQUAL 0x07
  spi1_busy = true;                                      // the IMU ISR defers to loop() meanwhile (no GPIO IRQ masking)
  uint64_t t = now_cyc();
  uint8_t motion = page_reg(0x02);
  int16_t dx = (int16_t)(page_reg(0x03) | (page_reg(0x04) << 8));
  int16_t dy = (int16_t)(page_reg(0x05) | (page_reg(0x06) << 8));
  uint8_t squal = page_reg(0x07);
  PagePayload p = {};
  p.seq = page_seq++;
  p.t_cyc = t;
  p.dx = dx;
  p.dy = dy;
  p.squal = squal;
  p.valid = (motion & 0x80) ? 1 : 0;
  push_frame(T_PAGE, &p, sizeof(p));
  spi1_busy = false;
  if (imu_pending) { imu_pending = false; imu_read_frame(imu_pending_t); }
}

// ------------------------------------------------------------------------------------------ host commands
static void send_config() {
  char s[255];
  snprintf(s, sizeof(s), "fw=%s;f_cpu=%lu;adc_rate=%lu;osr_code=%u;gain_codes=%u,%u,%u,%u,%u,%u,%u,%u;cam_div=%lu;"
           "strobe_delay_us=%lu;strobe_width_us=%lu;sync_w0_us=1000;sync_dw_us=250;tc_mask=%u",
           FW_VERSION, (unsigned long)F_CPU_ACTUAL, (unsigned long)adc_rate, adc_osr_code, adc_gain_code[0], adc_gain_code[1],
           adc_gain_code[2], adc_gain_code[3], adc_gain_code[4], adc_gain_code[5], adc_gain_code[6], adc_gain_code[7],
           (unsigned long)cam_div, (unsigned long)strobe_delay_us, (unsigned long)strobe_width_us, tc_mask);
  push_text(s, T_CONFIG);
  snprintf(s, sizeof(s), "servo=KP %.4g KI %.4g KD %.4g KFF %.4g ILIM %.3g ISCALE %.3g trip_err %ld trip_pos %ld;tones=%u;sweep=%d",
           KP, KI, KD, KFF, ILIM_A, ISCALE_A, (long)trip_err, (long)trip_pos, n_tones, sweep_on ? 1 : 0);
  push_text(s, T_CONFIG);
}
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
void loop() {
  // drain the ring buffer to USB in chunks
  uint32_t h = rb_head, t = rb_tail;
  if (h != t) {
    uint32_t n = (h > t) ? (h - t) : (RB_SIZE - t);
    if (n > 2048) n = 2048;
    int avail = Serial.availableForWrite();
    if (avail > 0) {
      if ((uint32_t)avail < n) n = (uint32_t)avail;
      Serial.write(&rb[t], n);
      rb_tail = (t + n) & (RB_SIZE - 1);
    }
  }
  // host commands, one per line
  while (Serial.available()) {
    char ch = (char)Serial.read();
    if (ch == '\n' || ch == '\r') {
      if (line_n) { line[line_n] = 0; handle(line); line_n = 0; }
    } else if (line_n < sizeof(line) - 1) {
      line[line_n++] = ch;
    }
  }
  if (page_on && page_timer >= page_period_us) {
    page_timer -= page_period_us;
    page_poll();
  }
}

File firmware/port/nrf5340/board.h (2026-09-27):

/*
 * board.h - Rev A pin plan (electronics/gen/design_revA.py sheet_mcu) and
 * port-internal interfaces. Pin numbers are copied from the schematic
 * generator; peripheral routing and SAADC AIN mapping are VERIFY.
 */
#ifndef PEN_BOARD_H
#define PEN_BOARD_H

#include <stdbool.h>
#include <stdint.h>

#include "app.h"

/* port 0 */
#define PIN_ISNS_X_AIN 0         /* AIN0 / P0.04 */
#define PIN_ISNS_Y_AIN 1         /* AIN1 / P0.05 */
#define PIN_VBAT_AIN 2           /* AIN2 / P0.06 (VBAT/2) */
#define PIN_NTC_AIN 3            /* AIN3 / P0.07 */
#define PIN_VREF_AIN 4           /* AIN4 / P0.25 (VREF_ADC = 1.25 V) */
#define PIN_SPIA_SCK 8           /* P0.08 (SPIM4) */
#define PIN_SPIA_MOSI 9          /* P0.09 */
#define PIN_SPIA_MISO 10         /* P0.10 */
#define PIN_HALL_CS_N 11         /* P0.11 (SPIM4 hardware CSN) */
#define PIN_OPT1_CS_N 12         /* P0.12 */
#define PIN_IN1_X 19             /* P0.19 */
#define PIN_IN2_X 20             /* P0.20 */
#define PIN_IN1_Y 21             /* P0.21 */
#define PIN_IN2_Y 22             /* P0.22 */
#define PIN_DRV_SLEEP_N 23       /* P0.23 */
#define PIN_ACT_EN_REQ 24        /* P0.24 (R71 pull-down) */
#define PIN_OPT2_CS_N 29         /* P0.29 */
#define PIN_OPT3_CS_N 30         /* P0.30 */
/* port 1 */
#define PIN_IMU_CS_N 1           /* P1.01 */
#define PIN_SPIB_SCK 2           /* P1.02 */
#define PIN_SPIB_MOSI 3          /* P1.03 */
#define PIN_SPIB_MISO 4          /* P1.04 */
#define PIN_FAULT_N 7            /* P1.07 */
#define PIN_FAULT_CLR_N 12       /* P1.12 (R74 pull-up) */
#define PIN_HALL_ALERT_N 13      /* P1.13 */
#define PIN_CHG_DET 14           /* P1.14 */

/* scheduler.c */
extern pen_app_t g_app;
void sched_init(void);
void SAADC_IRQHandler(void);   /* 40 kHz current loop */
void EGU0_IRQHandler(void);    /* 2 kHz stage task */
/* hal_nrf5340.c */
void board_gpio_init(void);
void board_timebase_init(void);
void board_wdt_init(void);
void board_slow_adc_store(int16_t vbat_code, int16_t ntc_code);
/* sensors_nrf5340.c */
void sensors_init(void);
void sensors_read(pen_sensors_t *s);
/* log sink (ring buffer drained by the USB CDC task, not implemented) */
void board_log_sink(const uint8_t *rec, size_t len, void *ctx);
uint32_t board_log_read(uint8_t *dst, uint32_t max);
void board_usb_cdc_write(const uint8_t *data, uint32_t n);

#endif /* PEN_BOARD_H */

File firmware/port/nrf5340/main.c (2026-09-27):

/*
 * main.c - nRF5340 application-core entry. COMPILE-TESTED ONLY.
 * Order: safe GPIO levels -> time base -> application -> sensors ->
 * PWM/SAADC/DPPI scheduler -> watchdog -> sleep; all control runs in the
 * SAADC (40 kHz) and EGU0 (2 kHz) interrupts.
 */
#include "board.h"
#include "hal.h"

int main(void)
{
    board_gpio_init();
    board_timebase_init();
    const bool wdt = hal_reset_was_watchdog();
    pen_app_init(&g_app, PEN_PROFILE_BALANCED, wdt);
    pen_app_set_sink(&g_app, board_log_sink, NULL, true);
    sensors_init();
    sched_init();
    board_wdt_init();
    static uint8_t chunk[256];
    for (;;) {
        __asm volatile("wfi");
        /* background: research-log drain to USB CDC (112 kB/s at 2 kHz); BLE,
         * flash capture and the user interface are not implemented */
        const uint32_t n = board_log_read(chunk, sizeof(chunk));
        if (n > 0u) {
            board_usb_cdc_write(chunk, n);
        }
    }
}

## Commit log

2026-09-26 Parameter file, physics package, report recalculation and coupled simulator M1
    - config/parameters.yaml: versioned parameters with units, ranges, evidence status
    - stabpen/: frames and paper-plane Jacobian, contact statics, actuator scaling,
    synthetic handwriting/tremor generators, provenance, figure style
    - analysis/audit_recalc.py: reproduces all 37 worked numbers of the source report
    and computes corrected analyses (transverse contact load, holding power,
    axial accommodation, pressure modulation, delay with servo, IMU drift)
    - sim/pensim/: numba 6-DOF coupled simulator (housing on hand impedance, front-pivot
    lever stage, axial suspension, LuGre paper contact, coil electro-thermal,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
    [audit_checks.csv]
2026-09-27 Audit, evidence ledger, requirements, EM/CAD/flexure/thermal analyses, tuned estimators and nominal benchmark
    - docs/audit.md + docs/corrections.csv: 28 corrections to the source report with
    evidence, status and design consequence (all 37 worked numbers reproduce; the
    force sizing omits the transverse normal-reaction term; Jacobian needs compliance)
    - docs/evidence.csv: 246-row source ledger merged from eight research streams
    (search logs in docs/research/notes); research synthesis and ranked risk questions
    - docs/requirements.csv: 50 requirements with verification method and status
    - analysis/: magpylib actuator field models, lever-ratio sweep, configuration trade
    study (A-F), lumpe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
    [ACT_active_stabilisation.csv, AMF_actuators_materials.csv, CON_contact_kinematics.csv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]
2026-09-27 Rev A research electronics, v0.4.0 parameters, contact-feedforward fix, ICD, decisions, physics
    Electronics (proposed design, not built):
    - KiCad 8 schematic generated from a declarative spec (11 sheets, 148
    placements, symbols copied from the installed libraries); ERC 0 errors,
    1 accepted warning; KiCad netlist export matches the intended netlist
    (102 nets, 492 pins); PDF and BOM with VERIFY/SELECT status per line.
    - Drive/sense calculations: coil rewound to 6 ohm so the 3.3 V supply
    never binds inside the thermally allowed envelope (DEC-012); 40 kHz
    centre-aligned PWM; INA241 sense chain; current-loop bandwidth; timing.
    - ngspice drive-stage transient incl. coil short: trip 8.8 u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
    [actuator_x.kicad_sch, actuator_y.kicad_sch, battery_supply.kicad_sch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]
2026-09-27 Parameters v0.4.1: refill slides in carrier, wider actuator gap; tolerance, mass and inertia budgets; simulation report
    Mechanics (calculation on the CAD concept):
    - Tolerance stacks: with the whole lever sliding (kappa_s = 0) the coil
    paddle closes the 0.45 mm actuator gap at design load (contact
    probability 0.97). DEC-007 revised: axial suspension in the carrier
    (kappa_s = 1, lever-arm change compensated); gap 0.50 mm and tip travel
    0.60 mm keep >= 93 um RSS clearance on every face.
    - Rev A.1 CAD variant (pouch cell, 41 mm PCB). Mass budget with
    allowances and 10 % contingency: 34.2 g with a polymer rear barrel;
    centre of mass 74 mm (requirement 70 mm still violated).
    - Distrib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
    [grid.csv, mass_budget.csv, metrics.csv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]
2026-09-27 Nose-to-paper clearance fix (DEC-018) and dimensioned stage-A bench rig
    - Tolerance stack S6: the Rev A nose (6 mm OD tip 1 mm behind the ball)
    lies 2.1 mm below the paper plane at 35 deg and 1.2 mm at 50 deg.
    Rev A.1 moves the nose tip to 5 mm behind the ball (OD 5.2 mm,
    aperture 4.2 mm): clearance 0.6/2.1/4.4 mm at 35/50/75 deg with the
    stage at full travel. CAD and mass budget updated (33.2 g with a
    polymer rear barrel; CoM 76 mm, still above the 70 mm requirement).
    - Stage-A bench mechanism as parametric CadQuery (pen-scale nib, lever and
    gimbal, two commercial VCMs, hand-simulant disturbance stage,
    goniometer, dead-weight normal force, F/T-sensed platen on an XY
    stage) w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
    [bench_rig_assembly.step, mass_budget.csv, pen_revA1_assembly.step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]
2026-09-27 ML workstream final: synthetic pipeline, baselines, TCN, int8, bit-exact C export, MCU budget; ICD 5 v1.1
    Results (SIMULATION, synthetic data, 80 held-out writers): a small causal
    TCN reaches a residual ratio of 0.48 vs 0.76 for the best conventional
    estimator at matched false correction (<= 25 um), but the advantage
    largely vanishes under realistic mismatch (coupled-simulator realism set,
    3-15 Hz: 0.73 vs 0.77; out-of-range tremor 0.83 vs 0.87, n.s.).
    int8 costs nothing measurable; C inference bit-exact against the Python
    int8 reference on 20 000 windows (host and emulated Cortex-M33); 16.7 k
    MAC, 7.3 kB weights, 0.64 kB RAM.
    Contract changes adopted from these results (docs/icd.md 5 v1.1)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
    [fig_distribution_shift.csv, fig_example_trace.csv, fig_feature_course.csv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]
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2026-09-27 Consistency pass after the validation review; validation workstream final
    Validation (drafted, nothing executed): 29 experiments, 221 acceptance
    criteria (checker passes), prototype stages and gates, human study plan
    separating immediate assistance from lasting improvement.
    Fixes from its review of 33 inconsistencies (resolution log in
    validation/README.md 6.8):
    - Requirements: current limits, stops, current-loop rate, Hall sampling,
    feature limits, ML output fields corrected; REQ-ACT-001 and
    REQ-MECH-001 recorded as violated with the limiting numbers;
    experiment ids and file traces corrected; REQ-ENV-001..003 added with
    acceptance criteria.
    - Parameters v0.4.2: gimbal stiffness 80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
    [acceptance_criteria.csv, config_trade.csv, corrections.csv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]
2026-09-27 Simulation chain on parameters v0.4.2; gate diagnostic; docs and criteria updated
    - Re-ran sim/run_all.sh on v0.4.2 (pivot stiffness 80 N/m, coil-to-ambient
    130 K/W). The balanced tuning objective now selects the set the assertive
    objective already used, so KF-BAL = KF-ASR. The v0.4.1 inert set comes
    second (J 1.204 vs 1.151); the flip is documented as selection fragility
    (docs/sim_report.md s3.2).
    - New sim/diag_gate.py -> results/sim/gate_fraction.json: fraction of
    contact time with authority g >= 0.5. Selected set: 0.94 / 0.93 with
    9 / 10 Hz tremor, 0.15 on tremor-free handwriting and 0.52 on the
    feature course. Added to run_all.sh; it is the prediction for AC-B09-15.
    - Figu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
    [acceptance_criteria.csv, corrections.csv, grid.csv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]
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2026-09-27 Firmware review follow-up: ICD v1.3, parameters v0.4.3, thermal and headroom corrections
    Resolves on the upstream side the discrepancies D1-D12 found by the
    firmware workstream:
    - ICD v1.3 (docs/icd.md). D1: the Jacobian was printed inverted; it is
    Rot(phi) diag(J_t1, 1) Rot(rho). D2: the actuator force sign is
    -n Kf i at the tip. D7: gamma is tilt-dependent, so CAL_USER v2 stores
    r_n = K_n/k_ax. D8: optics run at 1 kHz. D4: the calibration
    container and the 0x04/0x05 payloads are defined, and the mode codes
    added. The page origin, 64-bit stroke time and boundary samples are
    documented as implemented. ML contract v1.2 adds confidence rule (5)
    and the status of the exported arte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
    [acceptance_criteria.csv, actuator_x.kicad_sch, actuator_y.kicad_sch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]
2026-09-27 ML: export the model without f_est (contract v1.1); ICD section 5 aligned
    - The exported int8 C artefact is now tcn_s_nofest. It takes the 64
    (dx, dy) increments only (TCN_CIN 2, generated ml/export/tcn_model.h,
    hash low32 0xa57d81f6). The first-layer columns that multiplied the
    zeroed f_est channel are removed at load, which leaves the
    predictions unchanged (0.0 um on five recordings, unit-tested).
    - quantize.py fed real f_est into calibration and reference for a model
    trained with f_est at zero; fixed.
    - Verified: 22 ML tests pass. C is bit-exact with the Python int8
    reference on 20 000 windows (40 000 outputs, 0 LSB), also checked
    independently by the lead with gcc -Werror.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
    [acceptance_criteria.csv, corrections.csv, requirements.csv]
2026-09-27 Firmware follow-up integrated; parameters v0.4.4 (D13, D14); app aligned with ICD v1.3
    - Firmware (60/60 cases, 1120 checks on host and emulated Cortex-M33,
    as reported by the firmware workstream):
    - CAL_USER v2 with tilt-dependent gamma;
    - a two-node thermal governor that prefers the coil NTC;
    - ML guard rule (5) with normalised confidence;
    - 0x04 records carrying the calibration payload only;
    - D1-D14 status table in firmware/README.md.
    Parameters and vectors are regenerated again after the v0.4.4
    simulation re-run (next commit).
    - v0.4.4:
    - core.py applies the magnet Br tempco at the magnet (structure)
    temperature, ambient over its short runs, instead of the coil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
    [requirements.csv]
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2026-09-27 Current-loop figures: 2 kHz implemented crossover, 2.3 kHz as the 50-degree limit
    CHECKPOINT, electronics README, physics P-17 and the EXP-B05
    prediction quoted 2.3-2.34 kHz as the current-loop crossover. That
    figure is the delay limit for 50 degrees of phase margin. The
    implemented loop (simulator, firmware and drive_sense v0.4.4) crosses
    at 2 kHz with 55.8 degrees. AC-B05-04 now predicts a pass from the
    firmware step test (125 us rise, about 2.8 kHz closed-loop). Also
    fixed in CHECKPOINT: the selection margin is 3-6 % and the friction
    rank correlation 0.51.
    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
    [acceptance_criteria.csv]
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2026-09-27 Pencil concept CAD (Rev P0, L and Q bender layouts) and 3D replay viewer source
    mechanics/cad/pencil_revP.py builds the pencil-class concept in CadQuery from
    config/pencil.yaml: skid nose, D1 refill in a rear gimbal driven at a front
    collar by two (L) or four (Q) piezo benders through leaf flexures, nose Hall
    sensor, rigid-flex board and 6.5 mm cell. It reports mass (11.5 g L, 12.1 g Q
    before wiring and margin), section clearances with the bender tips at their
    stops, and a swept interference check of the nib assembly (none). The skid
    ring radius must grow to 1.4 mm for the refill cone to clear the aperture at
    35 degrees. viewer/ holds the three.js replay page template and its build
    script; t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
    [pencil_revPL_assembly.step, pencil_revPQ_assembly.step]
2026-09-27 Page-sensor rate needed for guided mode; pencil concept draft; OPT-36
    sim/diag_page_sensor_rate.py sweeps the page-sensor rate and latency in M1
    guided mode (feature course, 6 Hz 0.3 mm tremor, IMU bridging between page
    samples): 30 Hz keeps only a quarter of the benefit (0.76 of the no-correction
    path error), 120 Hz with 10 ms reaches 0.42, 250 Hz and above 0.39. The only
    camera that fits a pencil nose (OVM6948, OPT-36) runs at 30 fps, so capture
    on paper at 8.9 mm is a development item. docs/pencil_concept.md is the
    integrating report for the pencil-class concept (draft; sections from the
    mechanism, AI-guidance and sim-to-real studies follow).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
    [evidence.csv]
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2026-09-27 Pencil concept: mechanism study integrated, CAD P0.1.2, 3D replay page
    - Mechanism study (analysis/pencil_mechanisms.py, sim/pencil model P1,
    docs/pencil_mechanisms.md): only a skid-grounded nib with four custom
    2.6 mm piezo plates works at 8.9 mm; a voice coil needs 2.4 W to hold
    the load behind the skid. Stage: +/-277 um under the design load,
    0.329 N at the nib, 192 Hz. Battery 0.83 h assisted with DRV2700 drivers,
    2.7 h with charge recovery, 4.1 h recording only. 10/10 tests pass,
    including an exact match with M1 when the stage is locked.
    - CAD P0.1.2 applies the study's fixes: 5 mm leaf span (plates start at
    z 23 mm, gimbal at z 62 mm, lever 1.363), four snubber frames per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
    [evidence.csv, pencil_revPL_assembly.step, pencil_revPQ_assembly.step]
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2026-09-27 Pencil concept recorded in the decision log, requirements and README
    - DEC-019 skid-grounded writing force with a four-plate piezo stage;
    DEC-020 AI as digital autocorrect first, physical guidance only for known
    templates; DEC-021 page sensor >= 120 Hz with <= 10 ms latency;
    DEC-022 tilt-adaptive front stop (proposed). DEC-008 points to the
    pencil concept for candidate D.
    - REQ-PNC-001 to 008 with current estimates; stroke at the tolerance and
    low-tilt corners, the page sensor and the touchdown tails are at risk.
    Acceptance criteria for them are still to be written (checker passes).
    - README: pencil concept in Start here, key conclusions, completion table,
    reproduce commands an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
    [requirements.csv]
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2026-09-28 Pencil and AI experiments in validation; tail metric per stroke
    Validation (EXP-Q01-Q08, A03, A02): 29 criteria covering REQ-PNC-001-008,
    and sim-to-real items 1-11 applied to EXP-B02/B03/B05 and AC-B09
    (G7-G9 as AC-B09-16-18). 256 criteria, 39 experiments; the checker passes.
    REQ-PNC-002 derived as F_c <= 0.14 N from REQ-PNC-003 (at risk).
    Touchdown tails are now measured as extra and missing ink per stroke
    against a rigid pen on the same writing (diag_touchdown_tails.py):
    1.15 mm with the tilt-range stop, 0.33 mm with a tilt-adaptive stop at
    0.30 mm margin, missing ink about 0.01 mm. REQ-PNC-006, EXP-Q08 and
    AC-Q08-01/03 follow the new definition; DEC-023 status updated.
    3D page: tail t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
    [acceptance_criteria.csv, requirements.csv]
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2026-09-28 Inertial and pivot stabilisation study integrated (hand-pen model H1)
    A hand-pen-paper model with pen tilt in a two-zone grip calibrated to
    HAP-26 (sim/handpen/, 21 tests) evaluates weights, tuned masses,
    gyroscopes, control-moment gyroscopes and reaction wheels in the cap,
    a motorised grip sleeve, and passive pivots at the paper and in the
    grip, alone and with the nib stage (docs/inertial_stabilisation.md).
    With perfect knowledge of the tremor (0.3 mm, 4-12 Hz): the best
    helper within 20 g leaves 0.85-0.97 of the ink error and takes half
    the cell; gyroscope pairs leave 0.87-0.92 at 25 g and 0.34 W; the
    stage alone leaves 0.18-0.43. Passive pivots trade writing for tremor
    about one for one.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
    [acceptance_criteria.csv, evidence.csv]
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2026-09-28 Accelerometer tracker and AI estimation study integrated; AI + physical architecture
    fusion/ (25 tests) models real IMU parts, pen rotation and the page
    sensor, and runs causal trackers through the pencil model's external
    mode. On the P1 test grid (seeds 200-203) an acceleration-domain
    Kalman filter fed directly by the 6-axis IMU, with gyroscope
    compensation, leaves 0.78 of the tremor-band ink error (frozen filter
    0.85). It no longer adds error on 0.1 mm tremor and draws 132-138 mW
    instead of 203 mW. A 20 s per-writer calibration gives 0.58-0.71 at
    8-12 Hz and 0.3 mm. The robust set keeps sharp writers' tremor-free ink
    within 21 um, where the frozen filter moved it 123 um. AI letter
    template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
    [acceptance_criteria.csv, evidence.csv, evidence_rows.csv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]
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2026-09-28 Touchdown and lift optimisation: stage feed-forward, stop margin, servo retune
    opt/touchdown: a stage feed-forward that pre-positions the stage while the
    refill rests on its stop, cancels the measured slide after removing the part
    the stage causes, switches the contact-load bias at contact with integrator
    hand-over, and detects contact early from the Hall error. The structure was
    chosen with adjoint gradients of a differentiable reduced model; the eleven
    parameters and the margin by ParEGO on the pencil model P1. Tail ink falls
    from 0.11 to 0.008 mm per stroke at 50 deg (SIM, test seeds). The servo
    retune gives 19.3 -> 12.5 um tracking at 136 -> 117 mW with the margin rule
    kept. The simulato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
    [acceptance_criteria.csv, evidence.csv, requirements.csv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]
2026-09-28 Tracker optimised by exact adjoint gradients; optimisation entry page
    opt/tracker: the accelerometer Kalman filter rewritten in PyTorch (matches
    the numba filter to 1e-13) with a hand-written numba adjoint (2e-11 against
    autograd, 40x faster). Gradient descent through the filter re-optimises the
    random search's own robust objective: tremor-band ratio 0.86 against 0.91,
    0.67 against 0.79 at 8-12 Hz, sharp-writer shift 18 against 21 um (SIM,
    test seeds). The adjoint sweep maps the benefit/false-correction front;
    learned trackers retrained on the tremor band are not better at equal
    false correction and are not shipped. A recorded-data pipeline is ready
    for EXP-E01.
    Integration: DEC-028 (propos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
    [acceptance_criteria.csv, evidence.csv, fig_tr_pareto.csv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]
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2026-09-28 Guidance board study integrated (DEC-031, proposed optional accessory)
    board/: permanent-magnet head on a CoreXY stage under 3 mm glass pulls one
    small magnet in the pen's fixed sleeve; Hall-ring sensing of the pen's own
    magnet; 0.4 N software cap with fading and unassisted catch trials. 1.2 N
    available in every direction at the A4 gap, no holding power, about 25 Hz
    and 8 ms (CALC). Tracing error 1.49 -> 0.63 mm with full guidance, PD
    write-big loops 0.83 -> 0.93 of target; a determined wrong letter is not
    overpowered, a relaxed hand can be led (SIM). Ledger AMF-90..99,
    HAP-51..54, PAT-26..27; concept document section updated.
    Claude-S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
    [evidence.csv]
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2026-09-28 Rev H active nose (DEC-032) and inertial module in the first prototype (DEC-033)
    opt/inertial: architecture B (skid ring on the fixed sleeve carries the
    writing force; the nose tilts on a flexure gimbal so the ball moves +/-3 mm;
    flat voice coils react against the handle) beats A on every simulated
    criterion. Causal ratio 0.64/0.70/0.76 at 8-12 Hz, 1-2 mm (r_rot 0.3/0.5/0.7),
    ceiling 0.09-0.24 with perfect knowledge, 0.081 W (about 27 h), 75 g.
    The rear tungsten module adds 6/17/17 %; at the user's direction it is
    fitted in the first prototype, and the product decision follows the grip
    measurement (DEC-033 supersedes DEC-024). A passive weight worsens many
    cases; a CMG is out of budget. Ledg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
    [evidence.csv]
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2026-09-28 Rev H front end closed over 35-75 deg of tilt (DEC-034)
    The first layout drew the skid ring as a 15.9 mm tube 1.5 mm ahead of its
    contact plane, so the 3-D views showed it 1.5-3 mm below the paper; and
    the model's 5.5 mm contact radius left no room for the ring's wall at the
    nose's stop, with the nozzle reaching the paper at steep tilts.
    - opt/inertial/front_end.py (CALC): checks ring lip, nose-to-ring and
    nozzle-to-paper clearances, sleeve front and refill slide over 35-75 deg
    and every direction of tip travel; sizes the contact radius at 6.75 mm
    (lip wall 1.16 mm, nozzle >= 0.80 mm above the paper, ball travel
    >= 2.75 mm). The refill must slide about 13.5 mm: a constant-force stri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
    [evidence.csv, fig_front_end.csv, fig_in_cad.csv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]
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2026-09-28 AI help for severe tremor: study integrated (DEC-035)
    docs/ai_severe_tremor.md, aiprior/ and results/aiprior/ (model HW1, test
    writers 0-5, seeds 200-203, 216 scenarios; rules fixed on tuning writers):
    - AI letter prediction does not close the tracker's gap at 1-2 mm tremor:
    as a tracker prior 0 % (2 % even with the known text), as nose guidance
    1 % (12 % toward a known text); a wrong letter at full confidence made
    3-8 of 3744 letters read wrongly. Correct templates are 535-938 um off
    because they are anchored where the shaking tip lands. Not adopted.
    - The app's digital clean copy reads 97 % of words at 1-2 mm (ink 30-59 %)
    and leaves tremor-free writing unchanged: proposed for th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
    [acceptance_criteria.csv, evidence.csv, evidence_rows.csv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]
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2026-09-29 Rev J integrated design (round 2) and nose evidence ids tidied
    revj/, docs/revJ_design.md, results/revJ/ (layout, budgets, sim params,
    front end, refill, magnetics), mechanics/cad/revJ_pen.py with and without
    the end-cap; 23 tests and 38 fit checks pass. nose2 no longer generates the
    rows the ledger keeps under studies D and L (HAP-62, HAP-90..92).
    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
    [drawing_revJ_pen.csv, drawing_revJ_pen_no_endcap.csv, evidence_rows.csv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]
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2026-09-29 Validation pass 3 (DEC-044): REQ-RVJ-I01..I06, EXP-J01..J09, 422 criteria; board magnet noted in DEC-044; two requirement wordings fixed
    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
    [requirements.csv]
2026-09-29 Rev J.1 (round 3): gimbal, battery, heat, mass, visibility and detent fixes; DEC-045; 8 ledger sources; concept, README and checkpoint updated
    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
    [drawing_revJ1_pen.csv, drawing_revJ1_pen_no_endcap.csv, evidence.csv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]
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2026-09-29 Study M (measurement rigs) integrated: six rigs R9-R14 for gates G1-G5 and page sensing, CAD, DAQ firmware (not compiled), analyses and self-test; 31 ledger rows (620); DEC-058 (G1 on R9, axial and n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
    [bom.csv, evidence.csv, evidence_rows.csv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]
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2026-09-29 Study R (real recorded data) integrated: real handwriting, real PD and ET tremor, measured-error page sensor on held-out writers and patients; no tracker helps on real tremor yet (severe: 0.5 -> 0.4 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
    [evidence.csv, evidence_rows.csv, fig_before_after_chartraj_et_moderate.csv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]
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2026-09-30 Study B (balanced nib) integrated: DEC-050 (the B1 translation nib with a contact-driven counter-face carries the static side load: holding at most 1.6 mW, 7.6 mW continuous, about 38 h per charge, C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
    [bnib_assembly.step, evidence.csv, fig_sim_cards.csv]
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2026-09-30 Validation pass 9 (study B): REQ-BNIB-001..017; B20-B32 merged into the rig experiments (J17 part c, T01, T02, T04, T07-T10, T13, T15) or kept (B25, B28, B30, B31); C1S and autowrite requirements sco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
    [acceptance_criteria.csv, requirements.csv]
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2026-09-30 Validation pass 11 (study K, Rev K): 603 criteria, 178 experiments, 177 requirements (checker passes; 42 tests pass)
    - REQ-RVK-001..005 (envelope; battery >= 16 h per writing mode and 8 h lead-through; the couple without wire buckling; coil leads <= 0.3 ohm and fatigue with current; coil clearance at the stop and in drops).
    - REQ-BNIB-002 reworded per DEC-064 (1.0 mm at 35 deg without a float brake, 0.25 mm with one) and REQ-BNIB-011 per DEC-062 (rests on its stop, writes like a normal pen); notes on REQ-BNIB-017, REQ-RVJ-N06, REQ-RVJ-I01; AC-P01-06 now tests REQ-RVK-002.
    - EXP-K20, K21 (with the beryllium handling rule), K23, K25 (bench_protocols.md s53) and K24 (human_study_plan.md s24); K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
    [acceptance_criteria.csv, requirements.csv]
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2026-09-30 Study F (the readable target) integrated: DEC-067..069, reach notes on DEC-050/060, claims, ledger (702), README, CHECKPOINT, start page; explainer v11
    - DEC-067: a severe-tremor tracker must leave at most about 0.55 mm at the tip for +2 readable words (0.65 mm tuning, 0.55 mm test; 0.25 mm for near-normal reading); DEC-055 stays the pass line. DEC-068: per-user gates calibrated raise-only (worst clean writing 493 -> 19 um, information only). DEC-069: invest in separating tremor from writing, then a drift-free position reference; not prediction or latency (a 4.9 ms prediction leaves 0.03 mm).
    - Reach (study F's check, SIM, tuning split): with +-1.0 mm even perfect knowledge gains 1.4 words a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
    [evidence.csv]
2026-09-30 Validation pass 12 (study F): 609 criteria, 182 experiments, 180 requirements (checker passes in both modes; 60 tests pass)
    - REQ-CTRL-018 (DEC-067: at most 0.55 mm left at the tip for a severe-tremor tracker; 0.25 mm for near-normal reading), REQ-CTRL-019 (DEC-068: raise-only per-user calibration), REQ-SNS-006 (DEC-069: a position reference's in-band error, hypothesis).
    - EXP-E21, E22, E23 (bench_protocols.md s54) and EXP-E20 inside EXP-R03's panel (human_study_plan.md s25); AC-E10-03, AC-E11-03, AC-E20-01, AC-E21-01, AC-E22-01, AC-E23-01 (on REQ-BNIB-003).
    - Study F's simulation results recorded on AC-E13-01 (within), AC-E11-01 and AC-E11-02 (information only); the reach note (+-1.0 mm can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
    [acceptance_criteria.csv, requirements.csv]
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

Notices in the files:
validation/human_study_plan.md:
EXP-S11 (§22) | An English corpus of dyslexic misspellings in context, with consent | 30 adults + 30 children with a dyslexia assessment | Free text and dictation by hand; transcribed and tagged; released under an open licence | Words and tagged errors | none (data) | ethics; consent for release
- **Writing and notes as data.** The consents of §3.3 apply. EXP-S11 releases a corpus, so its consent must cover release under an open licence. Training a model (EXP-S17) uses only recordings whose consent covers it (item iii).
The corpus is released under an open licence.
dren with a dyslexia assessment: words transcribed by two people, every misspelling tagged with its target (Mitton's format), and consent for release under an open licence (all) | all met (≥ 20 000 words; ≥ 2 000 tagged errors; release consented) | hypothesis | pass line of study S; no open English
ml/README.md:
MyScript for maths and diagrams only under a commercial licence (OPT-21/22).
